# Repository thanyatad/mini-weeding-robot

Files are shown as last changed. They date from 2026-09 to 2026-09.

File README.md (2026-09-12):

# Mini Smart Weeding Robot

POC หุ่นยนต์เกษตรแบบ **rover 4 ล้อ วิ่งระหว่างแถวปลูก** —
NVIDIA Isaac Sim + Python + Computer Vision + Raspberry Pi + ESP32

เป้าหมาย: เริ่มพัฒนาจาก Simulation ก่อน แล้วเปลี่ยนไปใช้ Hardware จริงภายหลัง
โดยไม่ต้องรื้อ architecture หลัก

---

## First MVP — วิ่ง + มองเห็น

MVP แรกทำสองอย่างเท่านั้น: **เดินตามร่องด้วยกล้อง** และ **ตรวจจับวัชพืชในร่อง**

```text
✓ เดินตามร่องระหว่างแถวปลูกด้วยกล้องหน้า
✓ ตรวจจับวัชพืชในร่องด้วยกล้องล่าง แล้วบันทึก log
✗ ไม่กำจัดวัชพืช — ไม่มี tool ไม่มี servo
```

การกำจัดวัชพืชอยู่ที่ **M3** พร้อมงาน tool ทั้งชุด — ดู [Roadmap](#roadmap)

เหตุผล: mobility + perception เป็นความเสี่ยงที่ยังไม่ถูกพิสูจน์
แก้ทีเดียวพร้อม actuator จะแยกไม่ออกว่าอะไรพัง

Design เต็ม: **[docs/superpowers/specs/2026-09-12-rover-base-v0-scale-up-design.md](docs/superpowers/specs/2026-09-12-rover-base-v0-scale-up-design.md)**

Scale-up เป็นเครื่องภาคสนามขนาดจริง (650 × 520 mm, ล้อ Ø250, ~35 kg — ไม่ใช่
เครื่องเดโมบนโต๊ะ 145 mm เดิม): **[docs/superpowers/specs/2026-09-12-rover-base-v0-scale-up-design.md](docs/superpowers/specs/2026-09-12-rover-base-v0-scale-up-design.md)**

---

## Core Principle

> Controller ต้องไม่รู้ว่ากำลังควบคุม Simulation หรือ Hardware จริง

```text
Simulation != Controller
Controller != Hardware
Hardware   != Perception
Perception != Simulation
```

ทุก layer เชื่อมกันผ่าน **Interface** เท่านั้น

หลักการนี้รอดจากการเปลี่ยน form factor ทั้งเครื่อง — ตอนเลิก gantry มาใช้ rover
`Rover`/`CameraSet` interface ถูกเขียนใหม่ แต่ **pattern การเลือก backend
และเส้นแบ่งชั้นไม่ต้องแตะเลย**

---

## High-Level Architecture

```text
     ┌──────────────────────┐      ┌──────────────────────┐
     │   camera_front       │      │    camera_down       │
     │   row following      │      │   weed detection     │
     └──────────┬───────────┘      └──────────┬───────────┘
                ▼                             ▼
     ┌──────────────────────┐      ┌──────────────────────┐
     │    RowEstimate       │      │     Detection[]      │
     └──────────┬───────────┘      └──────────┬───────────┘
                ▼                             ▼
     ┌──────────────────────┐             weed_log
     │      Controller      │        (observation path)
     │  RowFollower         │
     │  State Machine       │
     │  Safety              │
     └──────────┬───────────┘
                ▼
     ┌──────────────────────┐
     │   Rover Interface    │   drive(v, omega) · stop() · emergency_stop()
     └──────────┬───────────┘
    ┌───────────┴───────────┐
    ▼                       ▼
┌─────────────┐     ┌─────────────┐
│ IsaacRover  │     │ Esp32Rover  │
└──────┬──────┘     └──────┬──────┘
       ▼                   ▼
 Isaac Sim            ESP32 (serial)
                           │
                  ┌────────┼────────┐
                  ▼        ▼        ▼
             H-bridge  E-stop   Watchdog
                  │     sense
                  ▼
         DC gear motor × 4  (skid-steer)
```

---

## The Machine

Rover skid-steer 4 ล้อ วิ่งในร่องระหว่างแถวปลูก

```text
Bed                       2000 × 1000 mm
Crop rows                 3 แถว ตามยาว
row_spacing               750 mm      กึ่งกลางแถวถึงกึ่งกลางแถว
clear furrow              690 mm      ◄── ค่าที่ rover ใช้จริง
Soil                      heightfield ผิวไม่เรียบ ±15 mm ไม่ยุบตัว
Rover                     skid-steer 4WD · เครื่องภาคสนาม ~35 kg · กว้างรวมล้อ 520 mm · ล้อ Ø250 mm
Cameras                   front (nav, ไม่ calibrate) + down (detect, homography) — ทั้งคู่บน mast เดียวกัน
Compute                   Raspberry Pi 5 ← serial → ESP32
```

**machine class**: นี่คือเครื่องภาคสนามขนาดจริง (650 × 520 mm, ~35 kg) ไม่ใช่
เครื่องเดโมบนโต๊ะขนาด 200 × 145 mm ของรอบพัฒนาก่อนหน้า — ตัวเลขทุกตัวในเอกสารนี้
คือของ Rover Base V0 ดู [scale-up design](docs/superpowers/specs/2026-09-12-rover-base-v0-scale-up-design.md)

**`row_spacing` ไม่ใช่ความกว้างที่ rover วิ่งได้** — ใบพืชยื่นเข้ามาข้างละ ~30 mm
ค่าที่ใช้จริงคือ `clear_furrow = row_spacing − 2 × crop_foliage_half_width`
invariant ทุกข้อที่เกี่ยวกับช่องว่างด้านข้างใช้ค่านี้

---

## ไม่มี Odometry — และผลที่ตามมา

MVP ไม่มี encoder ไม่มี localization ไม่มีแผนที่ ผลที่ต้องรู้ก่อนเขียน code:

```text
ไม่มี get_position()         ไม่มีอะไรตอบได้
ไม่มี drive_distance(mm)     จะ implement ได้แค่ velocity × time ซึ่งอ้างความแม่นที่ไม่มีจริง
ไม่มีพิกัดวัชพืชในแปลง        weed_log นับ "การตรวจจับ" ไม่ใช่ "จำนวนต้น"
โซ่ frame ขาดที่ bed → rover  ทุกอย่างใต้ rover ทำงานใน rover frame เท่านั้น
```

ใครเขียน code ที่ต้องการพิกัดใน `bed` frame ต้องหยุดแล้วไปทำ **M2 (encoder)**
ไม่ใช่เดาค่ามาเติม — ดู [hardware/mechanical/coordinate-frames.md](hardware/mechanical/coordinate-frames.md)

---

## Safety — 3 ชั้น 3 เจ้าของ

| กลไก | เจ้าของ | เงื่อนไข trip |
|---|---|---|
| Command timeout | **ESP32 firmware** | ไม่ได้รับ velocity command เกิน `command_timeout_ms` |
| Row-loss watchdog | **controller** | estimate invalid ติดกัน `row_loss_frames` |
| Latching E-stop | **hardware** | คนกด — ตัด motor rail ทางไฟ |

**แต่ละชั้นทำงานได้โดยไม่ต้องพึ่งชั้นบน** — Pi แครช มอเตอร์ก็ดับ ·
firmware แฮงค์ ก็ยังตัดไฟได้ ถ้าชั้นใดพึ่งชั้นบน มันไม่ใช่ safety layer มันคือ feature

MVP **ไม่มี bumper switch** ตัวชดเชยคือ `runaway_budget_mm` ที่ validate ตอน startup
+ ขอบแปลงยกสูงกว่าล้อ + ความเร็วต่ำ

---

## Startup Invariants

ความปลอดภัยที่พึ่งตัวเลขใน config ต้องถูก validate ตอน startup ไม่ใช่หวังว่าจะตั้งถูก

```text
safety      v_max × command_timeout/1000        <= runaway_budget         48 <= 60
safety      v_max × row_loss_frames/loop_hz     <= runaway_budget         48 <= 60
geometry    wheel_diameter        >= 4 × soil_variation                  250 >= 60
geometry    chassis_clearance     >  soil_variation                      125 >  15
geometry    clear_furrow          >  body_width + 2 × runaway_budget     690 > 640
drive       v + omega_max_rad × track/2  <= wheel_v_max               253.8 <= 327
drive       v − omega_max_rad × track/2  >= wheel_v_min                66.2 >=  51
config      gains[backend] ไม่เป็น null
consistency simulation.soil.variation_mm == bed.soil_variation_mm
```

ทุกข้อ fail = **ไม่ start** + บอกค่าที่ขัดกันเป็นตัวเลข ไม่ใช่ warning

ตัวเลขในโปรเจกต์นี้ถูกแก้หลายรอบเพราะ invariant จับได้ตอนร่างเอกสาร ไม่ใช่ตอน debug —
รอบ MVP เดิม (เครื่อง 145 mm): `row_spacing` (250 → 350) · `omega_max`
(60 → 40 เพราะ deadband มอเตอร์) · นิยามข้อ 5 (`row_spacing` → `clear_furrow`
เพราะใบพืชกินร่อง) · `track_width` (140 → 120 เพราะ `body_width` ต้องหมายถึง
ความกว้าง**รวมล้อ** ไม่ใช่แค่แชสซี) — รอบ scale-up นี้ (เครื่อง 520 mm):
`row_spacing` (350 → 750) · `track_width` (120 → 430) · `omega_max`
(40 → 25 ที่ track ใหม่) ดู [docs/superpowers/specs/2026-09-12-rover-base-v0-scale-up-design.md §7](docs/superpowers/specs/2026-09-12-rover-base-v0-scale-up-design.md)

ดู [config/README.md](config/README.md#startup-invariants) · [controller/README.md](controller/README.md#startup-validation)

---

## Repository Layout

| Path | Responsibility | Docs |
|---|---|---|
| `cad/` | parameters, exports, URDF — **ต้นทางของขนาดทุกตัว** | [cad/README.md](cad/README.md) |
| `hardware/` | เครื่องจริง — BOM, ขนาด, ประกอบ, สายไฟ, coordinate frames | [hardware/README.md](hardware/README.md) |
| `sim/isaac/` | Physics, แปลงดิน, sensor, rover model, simulation I/O | [docs/simulation.md](docs/simulation.md) |
| `controller/` | Robot brain — row follower, state machine, safety, startup checks | [controller/README.md](controller/README.md) |
| `perception/` | ExG, row estimator, weed detector, weed log, calibration | [perception/README.md](perception/README.md) |
| `firmware/esp32/` | Skid-steer mixing, command timeout, motor enable, E-stop sense | [docs/hardware.md](docs/hardware.md) |
| `bridge/` | Serial transport ระหว่าง Controller ↔ ESP32 / Simulation | [bridge/README.md](bridge/README.md) |
| `protocol/` | Message contract (JSON) shared by all layers | [docs/protocol.md](docs/protocol.md) |
| `config/` | YAML parameters — never hard-code in source | [config/README.md](config/README.md) |
| `tests/` | unit / integration / simulation / scenarios | [tests/README.md](tests/README.md) |
| `scripts/` | Run & flash entry points | [scripts/README.md](scripts/README.md) |
| `tools/` | Calibration, dataset, visualization utilities | [tools/README.md](tools/README.md) |

Full architecture rationale: **[docs/architecture.md](docs/architecture.md)**

---

## Asset Pipeline

Geometry ทั้งหมดเกิดที่ `cad/parameters/parameters.csv` แล้วไหลไป simulation —
ไม่มีใครวาดของซ้ำสอง CAD assembly (ซึ่งตอนนี้ยังไม่มี) **ไม่ใช่** ต้นทางของ geometry ที่ sim ใช้
(ดู [cad/README.md#pipeline](cad/README.md#pipeline) สำหรับรายละเอียดเต็ม):

```text
cad/parameters/parameters.csv          ◄── source of truth: geometry
   │
   ├── (sync)  ──> config/rover.yaml · hardware/mechanical/dimensions.md
   │
   ├── tools/generate_sim_meshes.py ──> cad/exports/meshes/ · cad/urdf/meshes/
   │                                     (generated — ห้ามแก้ด้วยมือ)
   │                                          │
   │                                          ▼
   │                                   cad/urdf/weeding_rover.urdf
   │                                          │  Isaac URDF importer
   │                                          ▼
   │                    sim/isaac/robots/rover/rover_base.usd    generated, gitignored
   │                                          │  + USD layer
   │                                          ▼
   │                    sim/isaac/robots/rover/rover.usd         physics tuning, commit
   │
   └── CAD assembly (งานมือ — ยังไม่มี) ────────> cad/exports/step/ · cad/exports/stl/
                                                       (สำหรับผลิตเท่านั้น)
```

**`parameters.csv` เป็นเจ้าของ geometry · `config/` เป็นเจ้าของ operational limits**
ค่าที่ derived จาก CAD มีตารางกำกับใน [cad/parameters/README.md](cad/parameters/README.md)
และมี `tests/unit/test_cad_config_sync.py` จับ drift

เส้นแบ่ง: *วัดด้วยเวอร์เนียร์ได้ = CAD · เปลี่ยนได้โดยไม่ต้องถอดสกรู = config*

⚠️ ข้อยกเว้นที่ rover มีแต่ gantry ไม่มี: **`camera_front_tilt_deg` ผูกกับ gain ของ controller**
มุมก้มกำหนด lookahead distance ขยับขายึดกล้องแล้ว gain ที่ tune ไว้ใช้ไม่ได้

---

## Backend Selection

Implementation ถูกเลือก **ตอน startup เท่านั้น** — ไม่มี `if simulation:` กระจายใน codebase

```yaml
# config/development.yaml
backend: isaac   # isaac | esp32 | fake
```

| Backend | Use case |
|---|---|
| `fake` | Unit test, closed-loop row following โดยไม่เปิด Isaac |
| `isaac` | Software-in-the-Loop, simulation test, digital twin |
| `esp32` | Hardware-in-the-Loop และ Real machine |

---

## Development Phases

```text
V0  Fake Rover        → Rover interface, RowFollower, state machine, safety, protocol
                        + closed loop ด้วย FakeRover (ไม่ต้องมีกราฟิก)
V1  Isaac Simulation  → rover USD, physics tuning (งานหนักสุด), row estimator, scenarios
V2  Computer Vision   → weed detector กล้องล่าง + evaluation harness เทียบ ground truth
V3  ESP32 HIL         → firmware จริงบนโต๊ะ ล้อลอย — mixing, timeout, E-stop, deadband
V4  Real Hardware     → rover จริงในแปลงจริง — tune gain ใหม่, วัด runaway budget
```

**น้ำหนักงานย้ายจาก design เดิม**: gantry หนักที่ V2 (แยก crop/weed)
rover หนักที่ **V1** (physics ของล้อบน heightfield) — วางแผนเวลาตามนี้

### V0 ปิดลูปได้โดยไม่ต้องมีกราฟิก

```text
FakeRover        integrate (v, omega) → pose ภายใน    (kinematic only)
FakeRowSensor    pose + สมการเส้นร่อง → RowEstimate
RowFollower      RowEstimate → (v, omega)
                        └──> วนกลับเข้า FakeRover
```

ตอบคำถาม *"gain ชุดนี้ลู่เข้าไหม และแกว่งเกินร่องไหม"* ได้ในหลักมิลลิวินาที อยู่ใน CI ได้
ก่อนแตะ Isaac เลย

⚠️ `FakeRover` มี pose ภายใน แต่ **ห้าม expose ผ่าน `get_drive_state()`** —
ถ้าหลุดออกมา code ที่เขียนตอน V0 จะพึ่งพา pose แล้วพังทั้งหมดตอนเปลี่ยนเป็น `esp32`

### MVP Acceptance Criteria

```text
V0  ไม่ต้องมี Isaac
[ ] FakeRover closed loop: เริ่มเบี่ยง 60 mm + เอียง 15° → |lateral_err| < 0.1 ใน 3 s
[ ] ระหว่างลู่เข้า ไม่มีจังหวะที่ระยะถึงต้นพืชติดลบ
[ ] golden mixing vectors ผ่านทั้ง Python และ firmware (native env)
[ ] startup invariant ทั้ง 9 ข้อ fail จริงเมื่อป้อนค่าที่ขัดกัน (test ละข้อ)
[ ] get_drive_state() คืน key ชุดเดียวกันทั้ง fake / isaac / esp32
[ ] ภาพดินเปล่า → exg mask ว่าง (ไม่ให้ Otsu แบ่ง noise)

V1  Isaac
[ ] rover วิ่งร่องตรง 2000 mm จบ ไม่เบียดต้นพืช
[ ] ร่องโค้ง 40 mm วิ่งจบ
[ ] เริ่มเอียง 15° เข้าร่องได้
[ ] ผิวดิน ±15 mm ยังตามร่องได้ (ล้อลอยเป็นช่วง)
[ ] ช่องว่างกลางแถว → ไม่หยุด
[ ] สุดร่อง → STOPPED(row_end_suspected)
[ ] ถอดแถวแต่ยังมีเขียว → ERROR(row_lost)
[ ] front loop >= 10 Hz
[ ] วัด max_lateral_error + crop_foliage_half_width จริง แล้ว re-validate invariant ข้อ 5

V2  Perception
[ ] weed detector per-frame precision >= 0.9
[ ] weed detector per-frame recall >= 0.8  (วัชพืชในร่องเท่านั้น)
[ ] วัดกับ randomization เปิดครบ ไม่ใช่ seed เดียว

V3  HIL — ล้อลอย
[ ] ถอดสาย serial → มอเตอร์ดับภายใน 300 ms (วัดด้วย scope หรือ log timestamp)
[ ] กด E-stop → ล้อหยุด ขณะที่ Pi ยังส่ง drive อยู่
[ ] ยัด drive 50 ตัวเข้า buffer → ESP32 ใช้ตัว seq สูงสุดตัวเดียว
[ ] ส่ง seq ย้อนหลัง → ถูกทิ้ง
[ ] วัด wheel_v_min_mm_s จริง แล้ว re-validate invariant drive ตัวล่าง

V4  แปลงจริง
[ ] 2 กล้องพร้อมกันบน Pi โดย front ยัง >= 10 Hz
[ ] tune gain esp32 แล้วบันทึกลง control.yaml (ไม่ใช้ค่า isaac)
[ ] วัด runaway distance จริง <= runaway_budget_mm
[ ] วัด homography error จริง บันทึกลง camera.yaml
[ ] วิ่งจบร่อง 2000 mm ในแปลงจริง 3 ครั้งติด
```

เกณฑ์ทุกข้อ **วัดได้** — ไม่มีข้อไหนเขียนว่า "ทำงานได้" โดยไม่บอกว่าวัดอย่างไร

---

## รั้วขอบเขต — สิ่งที่ MVP ไม่ทำ

เขียนไว้ชัดเพื่อไม่ให้ไหลเข้ามาทีละข้อ

```text
✗ ไม่กำจัดวัชพืช — ไม่มี tool ไม่มี servo
✗ ไม่เลี้ยวเข้าร่องถัดไป — วิ่งร่องเดียวแล้วหยุด
✗ ไม่มีพิกัดวัชพืชในแปลง — ไม่มี odometry
✗ ไม่ dedupe การตรวจจับ — log นับ detection ไม่ใช่นับต้น
✗ ไม่เห็นวัชพืชในแถว — เห็นแค่ในร่อง
✗ ไม่มี obstacle avoidance — ไม่มี bumper ไม่มี ToF
✗ ไม่มี turn-in-place — v = 0 กับ omega ใด ๆ อยู่ใน deadband ทั้งสองล้อ
✗ ไม่มี suspension
✗ ไม่มี ROS2 · ไม่มี MQTT · ไม่มี Wi-Fi ใน control path
```

---

## Roadmap

| M | เนื้อหา | ทำไมต้องลำดับนี้ |
|---|---|---|
| **M1** | **rover MVP — วิ่ง + มองเห็น** (ที่กำลังทำ) | พิสูจน์ mobility + perception ก่อนเพิ่ม actuator |
| **M2** | wheel encoder → ระยะตามแถว, dedupe, weed map | ต้องมาก่อน tool: tool ต้องเล็ง และการเล็งต้องรู้ตำแหน่ง |
| **M3** | tool + soil contact + in-row detection | ยกงาน tool จาก spec แปลงดินกลับมาใช้ได้เกือบทั้งหมด |
| **M4** | เลี้ยวเข้าร่องถัดไป → cover ทั้งแปลง | ต้องมี odometry จาก M2 ถึงจะเลี้ยวแบบไม่เห็นเป้าหมายได้ |
| **M5** | AI detector แทน ExG | dataset จาก M1–M3 มี background ดินจริงแล้ว |

---

## Technology Stack

| Component | Technology |
|---|---|
| Simulation | NVIDIA Isaac Sim |
| Controller | Python (บน Raspberry Pi) |
| Computer Vision | OpenCV / PyTorch |
| Firmware | ESP-IDF / Arduino |
| Firmware Build | PlatformIO |
| Communication | Serial (JSON lines) |
| Config | YAML |
| Protocol | JSON |
| Testing | pytest |
| Scenario Testing | YAML |
| Robot Model | USD |
| Version Control | Git |

---

## Why Not ROS2 (yet)

MVP นี้มี **1 หุ่นยนต์ 2 กล้อง 4 มอเตอร์ 1 E-stop** — ไม่มี SLAM ไม่มี path planning
ไม่มี MoveIt row following เป็น reactive controller ตัวเดียวที่รับ `RowEstimate`
คืน `(v, omega)` ไม่มี node graph ให้จัดการ

Python + Isaac Sim API + Rover abstraction ง่ายกว่าและเพียงพอ

ควรเพิ่ม ROS2 เมื่อมี: **Nav2 / SLAM จริง**, robot หลายตัว, sensor หลายชุด,
distributed process, hardware driver หลายชนิด, MoveIt / ROS Control

M4 (เลี้ยวเข้าร่องถัดไป + cover ทั้งแปลง) เป็นจุดที่ควรกลับมาทบทวนข้อนี้อีกครั้ง

---

## Design History

| Document | Status |
|---|---|
| [docs/superpowers/specs/2026-09-12-rover-base-v0-scale-up-design.md](docs/superpowers/specs/2026-09-12-rover-base-v0-scale-up-design.md) | **Current** — Rover Base V0, 650 × 520 mm, ล้อ Ø250 |

spec รุ่นก่อน (rover MVP ล้อ Ø70 และ gantry คร่อมแปลง) ถูกลบออกจาก tree แล้ว — อยู่ใน git history
| `mini-smart-weeding-table-repository-architecture.md` | ลบแล้ว — design โต๊ะ + ถาด อยู่ใน git history เท่านั้น |

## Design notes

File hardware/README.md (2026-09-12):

# hardware

เอกสารของเครื่องจริง — สิ่งที่จับต้องได้ ประกอบได้ และวัดได้

```text
hardware/
├── bom/
│   └── poc-v3.md               requirement envelope + ข้อกำหนดที่ต้องตรวจก่อนซื้อ
│
├── mechanical/
│   ├── dimensions.md           ขนาดทั้งหมด (derived จาก CAD)
│   ├── assembly.md             ลำดับประกอบ + ค่าที่ต้องวัดระหว่างทาง
│   └── coordinate-frames.md    นิยาม frame ทุกตัวในระบบ
│
└── electrical/
    ├── wiring.md               pin map + กับดักของ ESP32
    └── power.md                budget + topology + safety
```

---

## เริ่มอ่านจากไหน

| ถ้าคุณกำลัง… | อ่าน |
|---|---|
| ประเมินงบ / จะซื้อของ | [bom/poc-v3.md](bom/poc-v3.md) |
| ประกอบ rover | [mechanical/assembly.md](mechanical/assembly.md) |
| เดินสาย | [electrical/wiring.md](electrical/wiring.md) → [electrical/power.md](electrical/power.md) |
| เขียน firmware | [electrical/wiring.md](electrical/wiring.md) + [../docs/hardware.md](../docs/hardware.md) |
| เขียน perception / row follower | [mechanical/coordinate-frames.md](mechanical/coordinate-frames.md) |
| แก้ขนาด rover | [../cad/parameters/README.md](../cad/parameters/README.md) |

---

## `hardware/` กับ `docs/hardware.md` ต่างกันยังไง

| | ขอบเขต |
|---|---|
| `hardware/` | **เครื่องจริง** — ของที่ซื้อ, ขนาด, การประกอบ, สายไฟ, แปลงทดสอบ |
| `docs/hardware.md` | **firmware & integration** — ESP32 ทำอะไร, mixing, timeout, build/flash, HIL |

เส้นแบ่ง: *ถ้าต้องใช้ไขควง = `hardware/` · ถ้าต้องใช้ compiler = `docs/hardware.md`*

---

## เอกสารนี้ไม่ใช่ต้นทางของตัวเลข

ขนาดทุกตัวใน `mechanical/dimensions.md` เป็น **derived จาก CAD**

```text
cad/parameters/parameters.csv   ◄── ต้นทาง
   ├─► hardware/mechanical/dimensions.md   (เอกสาร)
   ├─► config/rover.yaml                   (runtime)
   ├─► cad/urdf/weeding_rover.urdf         (simulation)
   └─► config/drive_mixing_vectors.csv     (firmware + sim)

CAD assembly (ยังไม่มี) ──► cad/exports/step/ · cad/exports/stl/   (งานผลิตเท่านั้น)
```

ถ้าตัวเลขที่นี่ขัดกับ `parameters.csv` → **CSV ถูก** แล้วเอกสารนี้ล้าสมัย

ตรวจ drift ด้วย:

```bash
pytest tests/unit/test_cad_config_sync.py
```

---

## ค่าที่เอกสารชุดนี้ยัง **เดา** อยู่

ตัวเลขในเอกสารชุดนี้เป็นค่าเริ่มต้นที่สอดคล้องกัน ไม่ใช่ค่าที่วัดจากของจริง
ห้าเก้าค่าต่อไปนี้ต้องวัดแล้วเขียนกลับก่อนเชื่ออะไรที่สืบทอดจากมัน

| ค่า | วัดที่ | ถ้าผิดแล้วเกิดอะไร |
|---|---|---|
| `wheel_v_min_mm_s` | V3 ล้อลอย | `omega_max` สูงเกิน ล้อข้างในหยุดเงียบ |
| `body_width_mm` (จุดกว้างสุด) | หลังใส่ล้อ | invariant ข้อ 5 ผ่านโดยที่ล้อยังเบียดใบพืช |
| `chassis_clearance_mm` (พร้อมโหลด) | หลังประกอบครบ | ท้องครูดยอดดินที่ invariant บอกว่าผ่าน |
| `crop_foliage_half_width_mm` | V1 asset พืช | กระทบ invariant ข้อ 5 **และ** corridor พร้อมกัน |
| `soil_variation_mm` | หลังปรับหน้าดิน | เกิน 62 mm → invariant `wheel_diameter ≥ 4 × soil_variation` ไม่ผ่าน (ล้อ Ø250 ให้ margin 190 mm ที่ 15 mm — กว้างกว่าเดิมมาก ไม่ใช่จุดเสี่ยงหลักของเครื่องนี้แล้ว) |
| `runaway_budget_mm` | หลังวางลงแปลง | ค่าความปลอดภัยหลักของ MVP |
| FOV กล้องล่างจริง | ก่อนสั่งกล้อง | เห็นร่องไม่ครบ → ใบพืชผลถูกนับเป็นวัชพืช |
| `error_budget_mm` (homography) | หลัง calibrate | ตัวเลขใน weed log ไม่มีความหมาย |
| `gains.esp32` | V4 tune | ค้างเป็น `null` = ไม่ start (ตั้งใจ) |

---

## กับดักที่เอกสารชุดนี้เขียนไว้ให้แล้ว

เรื่องที่เสียเวลา debug มากที่สุดถ้าไม่รู้ก่อน — เรียงตามความเจ็บ

| เรื่อง | ที่ |
|---|---|
| **`omega` กลับด้าน → row follower เป็น positive feedback** | [electrical/wiring.md](electrical/wiring.md#ตรวจทิศทางก่อนปิดฝา) |
| **ESP32 กินไฟจาก Pi ทำให้ safety เหลือ 2 ชั้นไม่ใช่ 3** | [electrical/power.md](electrical/power.md#️-esp32-ต้องไม่กินไฟจาก-pi) |
| **Pi รีบูตตอนมอเตอร์ออกตัว (buck ตัวเดียว)** | [electrical/power.md](electrical/power.md#️-ต้องมี-buck-สองตัว--ไม่ใช่หนึ่ง) |
| **มอเตอร์เร็วเกินทำให้อยู่ใน deadband ตลอดเวลา** | [mechanical/dimensions.md](mechanical/dimensions.md#️-มอเตอร์ที่เร็วกว่า-แย่กว่า-ไม่ใช่ดีกว่า) |
| **`body_width` ≠ ความกว้างแชสซี (ล้อยื่นออก)** | [mechanical/dimensions.md](mechanical/dimensions.md#️-body_width--ความกว้างแชสซี) |
| **`camera_front_tilt` ผูกกับ gain — ไม่มี test จับ** | [mechanical/coordinate-frames.md](mechanical/coordinate-frames.md#️-แต่-extrinsic-ผูกกับ-gain) |
| ล้อซ้าย/ขวาคนละขนาด → ดูเหมือน gain ผิด | [mechanical/assembly.md](mechanical/assembly.md#ล้อคนละขนาดคือกับดักที่หายากที่สุด) |
| GPIO 34/35/36/39 ไม่มี internal pull-up | [electrical/wiring.md](electrical/wiring.md#️-gpio-34-35-36-39-ไม่มี-internal-pull-up) |
| E-stop ที่ตัด logic ด้วย → รายงานสถานะไม่ได้ | [electrical/power.md](electrical/power.md#e-stop-ตัดแค่-motor-rail) |
| soil reference plane ≠ ผิวดินจริง | [mechanical/coordinate-frames.md](mechanical/coordinate-frames.md#bed--ยังนิยามไว้-เพราะ-sim-และเอกสารต้องใช้) |
| mm ↔ m และ deg ↔ rad ที่รอยต่อ URDF | [mechanical/coordinate-frames.md](mechanical/coordinate-frames.md#unit-convention) |
| เสากล้องโยก → ภาพสั่น → `omega` กระตุก | [electrical/wiring.md](electrical/wiring.md#cable-management) |
| แบตอ่อน → deadband กินพิสัย `omega` แบบเงียบ | [electrical/power.md](electrical/power.md#low-voltage-behaviour) |

สามรายการบนสุดเป็นกลุ่มที่ **ทำให้ระบบดูเหมือนทำงานแล้วพังในแปลง** —
อ่านก่อนจ่ายไฟครั้งแรก

---

## ⚠️ MVP นี้ไม่ควรรันโดยไม่มีคนดู

```text
ไม่มี bumper switch
ไม่มี ToF / ultrasonic
ไม่มี obstacle avoidance
ไม่มี encoder จะรู้ว่าล้อหมุนจริงไหม
```

ตัวชดเชยทางกายภาพมีแค่สองอย่าง: **ขอบแปลงยกสูงกว่ารัศมีล้อ** และ
**`runaway_budget_mm` ที่ validate ตอน startup**

ถ้าขอบแปลงไม่ยก หรือ `runaway_budget` ยังไม่ได้วัดจริง — ต้องมีคนยืนถือ E-stop

ดู [../docs/superpowers/specs/2026-09-12-rover-base-v0-scale-up-design.md](../docs/superpowers/specs/2026-09-12-rover-base-v0-scale-up-design.md#12-risks--สิ่งที่ไม่มี-test-จับได้)

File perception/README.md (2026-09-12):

# perception

สอง pipeline แยกกันสมบูรณ์ แชร์เฉพาะ ExG

```text
                  ┌── exg.py (shared) ──┐
                  ▼                     ▼
camera.front ─> row_estimator.py    weed_detector.py <─ camera.down
                  │                     │
                  ▼                     ▼
             RowEstimate            Detection[]  ──> weed_log.py
             (control path)         (observation path)
```

**control path กับ observation path ต้องไม่ปนกัน** — detection ช้าหรือพลาด
ต้องไม่ทำให้ rover เลี้ยวผิด front ทำงานที่ 10 Hz · down ที่ 1-2 Hz

---

## Responsibility

- Camera input (2 ตัว)
- ExG segmentation
- Row estimate (navigation)
- Weed detection (observation)
- Weed log
- Calibration (กล้องล่างเท่านั้น)

**ไม่** รับผิดชอบ: motion, rover control, row following policy

---

## Layout

```text
perception/
├── cameras.py              # CameraSet interface + Fake / Isaac / Usb
├── exg.py                  # ExG + Otsu + absolute floor       shared
├── row_estimator.py        # front  → RowEstimate
├── weed_detector.py        # down   → Detection[]
├── weed_log.py             # JSONL writer
├── calibration.py          # intrinsic + homography (กล้องล่าง)
└── models/                 # trained weights — ว่างใน MVP (ใช้ที่ M5)
```

ไม่มี `row_detection.py` · ไม่มี `coordinate_transform.py` สำหรับ navigation —
เหตุผลอยู่ที่ [§weed_detector](#weed_detectorpy--เรขาคณิตของ-rover-ทำงานแทน-row-fitting)
และ [§Calibration](#calibration--เหลือแค่กล้องล่าง)

---

## CameraSet Abstraction

```python
class CameraSet(Protocol):

    def front(self) -> Frame:
        """สำหรับ row following"""
        ...

    def down(self) -> Frame:
        """สำหรับ weed detection"""
        ...
```

```text
CameraSet
│
├── FakeCameraSet
├── IsaacCameraSet
└── UsbCameraSet
```

เลือก **named accessor** ไม่ใช่ `capture(camera_id)` เพราะสองกล้องนี้ต่างกันที่
contract ไม่ใช่ต่างกันที่ index:

| | `front()` | `down()` |
|---|---|---|
| ใช้ทำ | row following | weed detection |
| Calibration | **ไม่ต้อง** | homography → mm |
| Rate | 10 Hz (อยู่ใน control loop) | 1-2 Hz |
| ความละเอียด | 640×480 → ย่อ 320×240 | 1280×720 |

`capture(id)` จะซ่อนความต่างนี้ แล้วมีคนเผลอเอาภาพ `front` ไปทำ coordinate transform

### `Frame` — ภาพที่รู้อายุตัวเอง

```python
@dataclass(frozen=True, eq=False)
class Frame:
    image: np.ndarray       # (h, w, 3) RGB
    timestamp_s: float      # monotonic clock ไม่ใช่ epoch
```

`camera_timeout_ms: 300` แปลว่าต้องมีใครสักคนตอบได้ว่าเฟรมนี้เก่าไปหรือยัง
stack ที่มี sensor จริงอยู่ข้างหลังตอบจาก**ตัวเฟรมเอง**ทั้งนั้น — ROS 2 ปั๊ม
acquisition time ลง header ของ `sensor_msgs/Image` · librealsense แขวน
`get_timestamp()` ไว้กับ frame object ข้อยกเว้นคือ `VideoCapture` ของ OpenCV
ที่คืน array เปล่าแล้วให้ไปถามเวลาแยกทาง `CAP_PROP_POS_MSEC` ซึ่งมีเอกสารว่า
คืน `-1` บนกล้องสด — **type alias เป็น ndarray เฉย ๆ คือ design นั้น**

นาฬิกาเป็น monotonic ไม่ใช่ wall clock เพราะคำถามเดียวที่ถาม timestamp คือ
ระยะเวลา ("เกิน 300 ms หรือยัง") และ wall clock เดินถอยหลังได้ตอน NTP แก้เวลา
ซึ่งจะทำให้ check ยิงใส่เฟรมสด หรือปล่อยเฟรมเก่าผ่าน

**`row_estimator.estimate()` รับ `np.ndarray` ไม่ใช่ `Frame`** — ROS แยกแบบเดียวกัน
คือ message พก header ส่วน `cv_bridge` ส่ง array เปล่าให้ algorithm estimator
ต้องการ pixel และไม่มีเรื่องต้องใช้นาฬิกา การใส่ field ที่มันห้ามอ่านลงใน
signature คือการชวนให้มีคนอ่าน

**คนเช็ค timeout ไม่ใช่ perception** `Event.CAMERA_TIMEOUT` อยู่ใน
`row_run.FAULT_EVENTS` ซึ่งเป็นชุดที่ detect *นอก* control loop — หน้าที่ของชั้นนี้
คือทำให้อายุเฟรม*รู้ได้* ไม่ใช่ตัดสินมัน

---

## `exg.py` — ExG + adaptive threshold + absolute floor

```python
exg = 2*G - R - B
if exg.max() < exg_floor:
    return Mask.empty()        # ไม่มีเขียวจริง — ไม่เรียก Otsu
mask = exg > otsu(exg)
```

### ทำไม ExG ไม่ใช่ color threshold ตรง ๆ

**ExG (Excess Green Index)** = `2G − R − B` วัด *ความเขียวเชิงสัมพัทธ์*
ไม่ใช่ค่าสีดิบ จึงทนต่อการเปลี่ยนแปลงของแสงและสีดินมากกว่า
เป็น index มาตรฐานในงาน agricultural vision

ดินแห้งกับดินเปียกสีต่างกันมาก — threshold คงที่บนค่าสีดิบต้อง tune ใหม่ทุกครั้งที่รดน้ำ

### ทำไม Otsu ต่อเฟรม ไม่ใช่ค่าคงที่

สีดินเปลี่ยนตามความชื้นและแสง Otsu หา threshold จากฮิสโทแกรมของเฟรมนั้นเอง
ไม่ต้องมีใครมาตั้งค่า

### ⚠️ จุดตายของ Otsu — และเหตุผลของ `exg_floor`

**เมื่อไม่มีสีเขียวในเฟรมเลย Otsu จะแบ่ง noise ออกเป็นสองกอง** แล้วคืน mask
ที่ดูเหมือนมีพืช ทำให้ heuristic `row_end` ตรวจไม่เจอว่าสุดร่องแล้ว

`exg_floor` เป็นพื้นกันข้อนี้ และเป็น **ค่าเดียวใน pipeline ที่ต้อง tune ด้วยมือ**

ต้องมี unit test ป้อนภาพดินเปล่ายืนยันว่าได้ mask ว่าง — อยู่ใน acceptance criteria ของ V0

---

## `row_estimator.py` — valley histogram ไม่ใช่ line fitting

สิ่งที่ rover ต้องตามคือ **ร่องดิน** ซึ่งคือหุบเขาระหว่างแถบเขียวสองแถบ

```text
column-wise green sum ของแถบภาพหนึ่งแถบ:

  ███                       ███        ← แถวพืชซ้าย / ขวา
  ███▄                     ▄███
  █████▄        ▼         ▄█████
  ───────────────────────────────────  u
              valley = กลางร่อง
```

สองแถบ สองหน้าที่:

```python
valley_near = find_valley(mask[bottom_third])    # ใกล้ล้อ
valley_far  = find_valley(mask[middle_third])    # lookahead

lateral_err = (valley_near - u_center) / (width / 2)
heading_err = (valley_far - valley_near) / (width / 2)
confidence  = valley_prominence                  # ความลึกของหุบเทียบยอดสองข้าง
valid       = confidence > conf_min  (ทั้งสองแถบ)
```

### `RowEstimate`

```python
@dataclass(frozen=True)
class RowEstimate:
    valid: bool
    lateral_err: float      # [-1, 1]  ร่องเบี่ยงจากกลางภาพ  (+ = ร่องอยู่ขวา)
    heading_err: float      # [-1, 1]  ความเอียงของเส้นร่องในภาพ  (+ = เอียงขวา)
    confidence: float       # [0, 1]
    green_fraction: float   # [0, 1]  สัดส่วน pixel ที่ ExG ผ่าน threshold
```

**ไม่มีหน่วย mm หรือ deg ทั้ง struct โดยเจตนา** — กล้องหน้าไม่ calibrate
ค่าที่วัดได้จากภาพที่ไม่ calibrate คือ pixel ratio ถ้าประกาศเป็น mm หรือ deg
จะเป็นการอ้างหน่วยที่ไม่มีใครยืนยันได้

gain ของ controller จึงมีหน่วย `(deg/s) / unitless` และ **ต้อง tune** —
ยอมรับตรง ๆ ดีกว่าซ่อนใต้หน่วยปลอม

### ทำไม valley histogram แทน line fitting / Hough

| | valley histogram | line fitting |
|---|---|---|
| ต้นหายกลางแถว | ทนได้ — histogram ยังเห็นแถบ | เสี่ยง fit เพี้ยนเพราะ blob หาย |
| ร่องโค้ง | ทนได้ — วัดสองระยะแยกกัน ไม่บังคับเป็นเส้นตรง | ต้อง fit เส้นโค้ง ซับซ้อนขึ้น |
| ต้นทุน | numpy sum + argmin ทัน 10 Hz บน Pi สบาย | Hough แพงกว่ามาก |
| Debug | plot histogram เห็นทันทีว่าพลาดที่ไหน | ต้องดู blob + parameter หลายตัว |

`heading_err` จากผลต่างของ valley สองระยะ **ไม่ต้องรู้ geometry กล้องเลย**

`valley_prominence` เป็น confidence ที่มีความหมายทางกายภาพ: ถ้าแถบเขียวสองข้าง
แยกจากหุบไม่ชัด แปลว่าไม่เห็นร่อง ซึ่งควรทำให้ `valid = False` จริง ๆ
ไม่ใช่ค่าที่ตั้งเอาใจให้ผ่าน

### ⚠️ ผูกกับ `camera_front_tilt_deg`

มุมก้มกำหนดว่า `valley_far` อยู่ห่างไปข้างหน้าเท่าไร = **lookahead distance**
ขยับขายึดกล้องแล้ว gain ที่ tune ไว้ใช้ไม่ได้ ดู [../config/README.md](../config/README.md#controlyaml)

---

## `weed_detector.py` — เรขาคณิตของ rover ทำงานแทน row fitting

design gantry ต้อง fit เส้นแถวเพื่อแยก crop จาก weed เพราะมองทั้งแปลงจากด้านบน
พืชผลกับวัชพืชอยู่ในเฟรมเดียวกัน

rover กลับด้านปัญหานี้: **กล้องล่างเล็งที่ร่อง และพืชผลไม่ได้ปลูกในร่อง**

```text
สีเขียวในร่อง = วัชพืช  โดยนิยาม
```

ไม่ต้อง classifier ไม่ต้อง row fitting ไม่ต้องเทียบขนาดกับพืชผล:

```python
mask = exg_mask(down_frame)
for blob in blobs(mask):
    if blob.touches_side_edge:                     continue   # ใบพืชผลที่ล้ำเข้ามา
    if blob.centroid_x_mm not in furrow_corridor:  continue
    if blob.area_mm2 < min_weed_area_mm2:          continue
    yield Detection(...)
```

### `furrow_corridor` มาจากเรขาคณิต

```text
clear furrow   row_spacing − 2 × crop_foliage_half_width   750 − 60 = 690 mm
corridor       clear_furrow − 2 × max_lateral_error_mm      690 − 80 = 610 mm
```

`corridor` คือแถบที่ **รับประกันว่าอยู่ในร่อง** แม้ rover เบี่ยงเต็มพิสัย —
สีเขียวในแถบนี้จึงเป็นวัชพืชได้โดยไม่ต้องรู้ว่าแถวอยู่ไหน

กฎ `touches_side_edge` จัดการใบพืชผลที่ยื่นเข้าร่องโดยไม่ต้องรู้ว่ามันคือพืชผล —
ใบที่ต่อเนื่องออกไปนอกเฟรมย่อมไม่ใช่ต้นเล็กที่อยู่กลางร่อง

### สองค่าที่ประกอบกันเป็น corridor ต้องวัดที่ V1 ทั้งคู่

| ค่า | ตั้งไว้ | ถ้าวัดจริงแล้วมากกว่า |
|---|---|---|
| `max_lateral_error_mm` | 40 | corridor แคบลง recall ตก |
| `crop_foliage_half_width_mm` | 30 | clear furrow แคบลง **กระทบ startup invariant ข้อ 5 ด้วย** |

ถ้าค่าที่วัดได้ทำให้ `corridor <= 0` แปลว่า **แปลงแคบเกินไปสำหรับ rover ขนาดนี้**
ไม่ใช่ว่า detector ต้อง tune ใหม่

### ข้อจำกัด: วัชพืชในแถวมองไม่เห็น

in-row weed เป็นกรณี**ยากที่สุด**ของปัญหาจริง และอยู่นอก MVP โดยเจตนา —
เพราะการกำจัดมันต้องมี tool ซึ่งไม่มีใน MVP อยู่แล้ว

**ไม่ควรทำให้ perception ยากกว่าที่ actuator ทำได้** กลับมาที่ M3 พร้อม tool

---

## Calibration — เหลือแค่กล้องล่าง

| | กล้องหน้า | กล้องล่าง |
|---|---|---|
| Calibration | **ไม่มี** | homography → soil reference plane |
| Accuracy target | – | **±20 mm** (ผ่อนจาก ±8 mm ของ design gantry) |

ผ่อนได้เพราะ **MVP ไม่มีอะไรกระทำต่อตำแหน่ง** — ไม่มี tool ที่ต้องเล็ง
ตัวเลข mm ใช้แค่บันทึกขนาด/ตำแหน่งคร่าว ๆ ใน log

แต่ยัง **ต้องทำ** homography ตอนนี้ ไม่เลื่อนทั้งหมด — เพื่อรู้ตัวเลข error budget จริง
บนดิน ±15 mm **ก่อน** ออกแบบ tool ที่ M3 ไม่ใช่หลังจากนั้น

ขั้นตอน: [../docs/calibration.md](../docs/calibration.md)

---

## `weed_log.py` — และข้อจำกัดที่ต้องไม่ให้ใครเข้าใจผิด

```jsonl
{"t":12.34,"frame":123,"lateral_err":0.12,"u":160,"v":200,
 "x_mm":-25,"y_mm":120,"area_mm2":480}
```

`x_mm` / `y_mm` เป็นพิกัด **ใน rover frame** ไม่ใช่ใน bed frame

### ไม่มี weed id และไม่มีพิกัดในแปลง

ไม่มี odometry จึงไม่มีทางรู้ว่าวัชพืชที่เห็นในเฟรม 123 กับ 124 เป็นต้นเดียวกัน
หรือคนละต้น

**log นี้นับ "การตรวจจับ" ไม่ใช่ "จำนวนวัชพืช"** — ตัวเลขรวมจาก log ไม่มีความหมาย
**ห้ามใช้เป็น metric**

### วัดด้วย per-frame precision / recall

```text
per-frame precision >= 0.9
per-frame recall    >= 0.8   (วัดเฉพาะวัชพืชในร่อง)
```

เทียบ ground truth ที่ Isaac รู้อยู่แล้ว — ได้ label ฟรีและวัดได้ทุกเฟรม

recall ตั้งต่ำกว่า precision **โดยเจตนา**: MVP ไม่กำจัดอะไร การพลาดต้นหนึ่ง
ไม่เสียหาย แต่การรายงานดินเป็นวัชพืชจะทำให้ threshold ถูก tune ผิดทางตั้งแต่ต้น

ต้องวัดกับ randomization เปิดครบ ไม่ใช่ seed เดียว

---

## Detection Roadmap

| Stage | Method |
|---|---|
| **M1 (MVP)** | OpenCV — ExG + Otsu + corridor geometry |
| M3 | + in-row detection (ต้องแยก crop/weed จริง ๆ ตอนนั้น) |
| M5 | AI — YOLO / segmentation model |

อย่าเริ่มด้วย Deep Learning — MVP นี้แยก crop/weed ได้ด้วย**เรขาคณิต**
ซึ่งอธิบายได้ debug ได้ และไม่ต้องมี dataset

Dataset สำหรับ M5 generate ได้จาก `tools/dataset/` โดยใช้ ground truth จาก Isaac Sim

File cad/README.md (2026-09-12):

# cad

> ### ⚠️ `cad/fusion/rover_base_v0.f3d` เป็น snapshot ไม่ใช่ working file
>
> Rover Base V0 (650 × 520, ล้อ Ø250) มี assembly แล้ว `exports/step/` และ
> `exports/stl/` ไม่ว่างอีกต่อไป
>
> ```text
> parameters.csv · urdf/ · exports/meshes/   ✓ generated จาก CSV
> fusion/ · exports/step/ · exports/stl/     ✓ มาจาก CAD assembly
> ```
>
> แต่ **ตัวที่แก้ได้อยู่บน Autodesk cloud ไม่ใช่ไฟล์ใน repo** — Fusion save ลง
> cloud project เสมอ ไม่เคย save กลับมาที่นี่:
>
> ```text
> เปิด .f3d  →  Fusion upload เข้า cloud  →  ได้ document ใหม่ คนละตัวกับไฟล์นี้
> กด Save    →  ลง cloud                  →  ไฟล์ใน repo ไม่ขยับ
> ```
>
> **แก้ assembly แล้วต้อง export ทับทั้ง 3 ที่เสมอ** (`fusion/` · `exports/step/` ·
> `exports/stl/`) ไม่งั้นมัน stale เงียบ ๆ — `7e91e59` ลบ `rover.f3d` ตัวเก่าทิ้ง
> เพราะค้างอยู่ที่รถ 200 × 145 ล้อ Ø70 ทั้งที่โปรเจกต์ย้ายไป 650 × 520 แล้ว
>
> `parameters.csv` ยังเป็นต้นทางของ geometry เหมือนเดิม — `.f3d` เก็บไว้กู้ **งาน
> ประกอบ** (user parameter, sketch, constraint) ไม่ใช่กู้ตัวเลขขนาด
>
> `exports/meshes/` **ไม่เกี่ยวกับงานนี้เลย** — `tools/generate_sim_meshes.py`
> สร้างจาก `parameters.csv` ให้แล้ว

Mechanical source of truth — **เรขาคณิตทั้งหมดต้นทางที่ `cad/parameters/parameters.csv`**
งานผลิต (STEP / STL) มาจาก CAD assembly ใน `fusion/` ดู [Pipeline](#pipeline) ด้านล่าง

```text
cad/
├── parameters/
│   ├── README.md               นิยาม parameter + ตาราง derived
│   └── parameters.csv          ต้นทางของ geometry — แก้ตรงนี้ (commit ทุกครั้งที่แก้ขนาด)
│
├── fusion/
│   └── rover_base_v0.f3d       snapshot ของ assembly — ตัวจริงบน cloud (ดูกล่องบนสุด)
│
├── exports/
│   ├── step/                   งานผลิต / review / ส่งร้าน
│   ├── stl/                    3D print
│   └── meshes/                 simplified visual + collision สำหรับ sim
│
└── urdf/
    ├── weeding_rover.urdf      links, joints, limits, mesh refs
    └── meshes/                 mesh ที่ URDF อ้างถึง
```

---

## Pipeline

`cad/parameters/parameters.csv` **คือต้นทางของ geometry** — ไม่ใช่ CAD assembly
สอง path ไหลออกจากมันแยกกัน และไม่มี path ไหนขึ้นกับอีก path (S11):

```text
cad/parameters/parameters.csv          ◄── source of truth: geometry
   │
   ├── tools/generate_sim_meshes.py ──> cad/exports/meshes/ · cad/urdf/meshes/
   │                                     (generated — ห้ามแก้ด้วยมือ)
   │                                          │
   │                                          ▼
   │                                   cad/urdf/weeding_rover.urdf
   │                                          │
   │                                          │  Isaac URDF importer  →  scripts/import_urdf.sh
   │                                          ▼
   │                    sim/isaac/robots/rover/rover_base.usd    ◄── generated, gitignored
   │                                          │
   │                                          │  + USD layer
   │                                          ▼
   │                    sim/isaac/robots/rover/rover.usd         ◄── override layer, commit
   │
   └── CAD assembly (งานมือ, บน cloud) ─> cad/fusion/rover_base_v0.f3d
                                          cad/exports/step/ · cad/exports/stl/
                                             (สำหรับผลิต / review / ส่งร้าน เท่านั้น)
```

`tools/generate_sim_meshes.py` อ่าน `parameters.csv` แล้วเขียน mesh + inertia
tensor ให้ sim โดยตรง — ไม่ผ่าน CAD assembly เลย เพราะงาน assembly เป็นงานมือ
ถ้า sim ต้องรอ งาน development จะหยุด `cad/exports/meshes/` และ
`cad/urdf/meshes/` จึงเป็นไฟล์ **generated** ห้ามแก้ด้วยมือ — แก้ที่
`parameters.csv` แล้วรัน generator ใหม่เสมอ

**path ล่างมีของแล้ว** assembly ขึ้นรูปจาก `parameters.csv` และผูก user parameter
ไว้ทุกตัว แต่มันยังตามมาทีหลังได้โดยไม่บล็อกใคร (design §9.1) — นี่คือเหตุผลที่ sim
ไม่ถูกผูกกับมันตั้งแต่แรก และยังไม่ควรผูก

### ทำไมต้องแยก 2 USD layer

URDF เก็บ **drive gain, damping, contact offset, friction, sensor attachment**
ของ Isaac ไม่ได้

ถ้าแก้ค่าพวกนี้ลงใน USD ที่ import มาโดยตรง แล้ววันหนึ่ง CAD เปลี่ยนแล้ว regenerate
→ tuning ทั้งหมดหาย

การแยก layer ทำให้ **regenerate `rover_base.usd` ได้ตลอดเวลาโดยไม่แตะ tuning**

| ไฟล์ | สถานะ | เจ้าของ |
|---|---|---|
| `rover_base.usd` | generated, **gitignored** | URDF importer |
| `rover.usd` | override layer, **commit** | คนปรับ physics ใน Isaac |

Friction ของล้อกับ heightfield เป็นค่าที่ tune ยากที่สุดของโปรเจกต์นี้ —
มันอยู่ใน `rover.usd` และเสียไปตอน regenerate ไม่ได้

---

## กฎการแก้ขนาด

เมื่อขนาดทางกายภาพเปลี่ยน ต้องทำครบทั้ง 3 ขั้นนี้ — ไม่ต้องรอ Fusion:

1. แก้ `cad/parameters/parameters.csv` โดยตรง แล้ว commit — มันคือต้นทางของ
   geometry (ดู [Pipeline](#pipeline) ด้านบน) **ไม่ใช่ export จาก Fusion**
2. รัน `tools/generate_sim_meshes.py` เพื่อ regenerate `cad/exports/meshes/`
   และ `cad/urdf/meshes/` — **ไม่ใช่ export mesh มือจาก Fusion**
3. Regenerate URDF → base USD (Isaac importer)

แล้วรัน:

```bash
pytest tests/unit/test_cad_config_sync.py       # จับ config/ ที่ยังไม่ตามขนาดใหม่
pytest tests/unit/test_generate_sim_meshes.py   # จับ mesh ที่ยังไม่ regenerate
pytest tests/unit/test_urdf_matches_cad.py      # จับ URDF ที่ยังอ้างขนาดเก่า
```

ทั้งสามข้อจับคนละจุดพัง เปลี่ยนขนาดครั้งเดียวอาจทำให้ข้อใดข้อหนึ่งพังโดยที่อีกสองข้อยังผ่าน
ต้องรันครบทั้งสาม — ไม่ใช่แค่ข้อแรก

ถ้า `test_cad_config_sync.py` fail แปลว่ามีค่าใน `config/` ที่ derived มาจาก CAD แล้วยังไม่ได้อัปเดต
ดูตาราง derived ใน [parameters/README.md](parameters/README.md)

**อย่าแก้ค่าใน `config/rover.yaml` เพื่อให้ test ผ่าน** ถ้าต้นเหตุคือ CAD เปลี่ยน —
ต้องตามให้ค่าใน config สะท้อนของจริง

### งานผลิต — แยกต่างหาก ไม่บล็อกงาน sim

STEP/STL งานผลิตเป็นคนละ track จาก 3 ขั้นข้างบน และตามทีหลังได้เสมอโดยไม่บล็อกใคร
(design §9.1) — sim ไม่ต้องรอ assembly

ขั้นตอนเมื่อแก้ assembly (เปิดตัวบน cloud ไม่ใช่ `.f3d` ใน repo):

1. แก้ผ่าน **user parameter** เท่านั้น — อย่าพิมพ์ตัวเลขลง sketch และอย่าใช้
   Move/Copy กับ body ทั้งสองอย่างตัดชิ้นนั้นขาดจาก `parameters.csv`
2. Export `cad/fusion/rover_base_v0.f3d` ทับ — **ขั้นนี้ลืมบ่อยที่สุด**
3. Export `cad/exports/step/` ชิ้นที่กระทบ
4. Export `cad/exports/stl/` เฉพาะชิ้นที่ต้องพิมพ์ใหม่

assembly เป็นเจ้าของ `fusion/`/`step/`/`stl/` เท่านั้น — ไม่ใช่ต้นทางของ
geometry และไม่มีอะไรใน sim ขึ้นกับมัน

---

## ⚠️ พารามิเตอร์ที่แก้แล้วกระทบมากกว่าที่คิด

rover มี coupling ระหว่าง CAD กับ software ที่ gantry ไม่มี

| แก้ค่านี้ | กระทบอะไรนอกจากรูปร่าง |
|---|---|
| `camera_front_tilt_deg` | **gain ของ row follower ใช้ไม่ได้** — มุมกำหนด lookahead distance |
| `camera_front_height_mm` | เหมือนกัน — ความสูงก็กำหนด lookahead |
| `wheel_diameter_mm` | `wheel_v_max_mm_s` เปลี่ยน → พิสัยของ `omega_max` เปลี่ยน → **invariant `drive` ทั้งสองข้อ** |
| `track_width_mm` | สูตร mixing เปลี่ยน → `config/drive_mixing_vectors.csv` ต้อง regenerate ทั้งตาราง |
| `body_width_mm` | **invariant ข้อ 5** (`clear_furrow > body_width + 2 × runaway_budget`) |
| `chassis_clearance_mm` | **invariant ข้อ 4** (`> soil_variation`) |
| `camera_down_height_mm` | coverage ของ corridor — ถ้าต่ำเกินจะเห็นไม่ครบร่อง |
| `chassis_plate_width_mm` | ถ้าเกิน track − wheel_width โครงชนล้อ — `test_the_chassis_plate_clears_the_inner_faces_of_the_wheels` |

`camera_front_tilt_deg` เป็นตัวที่เจ็บที่สุด เพราะ **ไม่มี test จับได้** —
`test_cad_config_sync.py` ตรวจว่าตัวเลขตรงกัน แต่ตรวจไม่ได้ว่า gain ยังเหมาะกับมุมใหม่
ต้องกลับไป tune ที่ V1 และ V4 ใหม่ทั้งคู่

(กล้องของ gantry มองตรงลงและอยู่กับที่ มุมไม่มีผลต่อ control เลย)

---

## Git LFS

ไฟล์ binary ในโฟลเดอร์นี้โตเร็วและ diff ไม่ได้ ควรใช้ Git LFS

```bash
git lfs install
git lfs track "*.f3d" "*.step" "*.stp" "*.stl" "*.usd" "*.usdc" "*.obj" "*.dae"
git add .gitattributes
```

ตั้งแต่ commit แรกที่มีไฟล์จริง — ย้ายทีหลังต้องเขียนประวัติใหม่ทั้ง repo

`parameters.csv` และ `.urdf` เป็น text **ไม่ต้องใส่ LFS** — ต้องการ diff ที่อ่านได้
เพราะมันคือที่ที่การเปลี่ยนขนาดจะปรากฏตอน review

---

## Boundary

✅ CAD เป็นเจ้าของ: track width, wheelbase, ขนาดล้อ, ความสูงท้องรถ, ความกว้างตัวถัง,
ตำแหน่งและมุมขายึดกล้อง, ตำแหน่งรูยึดมอเตอร์, mass / inertia

❌ CAD **ไม่** เป็นเจ้าของ: `v_max`, `omega_max`, timeout, gain, threshold,
`soil_variation_mm`, `runaway_budget_mm` — พวกนี้เป็น **operational** อยู่ใน `config/`

เส้นแบ่ง: *ถ้าวัดด้วยเวอร์เนียร์ได้ = CAD · ถ้าเปลี่ยนได้โดยไม่ต้องถอดสกรู = config*

### กรณีชายขอบ: `wheel_v_max_mm_s` และ `wheel_v_min_mm_s`

สองค่านี้ไม่ใช่ทั้ง CAD แท้และ config แท้:

```text
wheel_v_max_mm_s = (motor_rpm / 60) × pi × wheel_diameter_mm
                 = (25 / 60) × pi × 250
                 = 327 mm/s
```

`wheel_diameter_mm` เป็น CAD · `motor_rpm` เป็นสเปกของของที่ซื้อ (BOM)
ค่าผลลัพธ์อยู่ใน `config/rover.yaml` พร้อม comment ชี้ทั้งสองต้นทาง

`wheel_v_min_mm_s` (deadband) **วัดจากมอเตอร์จริงเท่านั้น** คำนวณไม่ได้ —
ค่า 51 ใน config เป็นค่าประมาณจาก 15% duty ต้องวัดจริงที่ V3

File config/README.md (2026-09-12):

# config

> อย่า hard-code parameter ใน source code

---

## Files

| File | Scope |
|---|---|
| `rover.yaml` | Rover geometry (derived: cad), drive limit, bed geometry |
| `safety.yaml` | Runaway budget, timeout, row-loss frames, E-stop |
| `perception.yaml` | ExG floor, confidence, loop rate, corridor, weed area |
| `control.yaml` | Row follower gain — **แยกตาม backend** |
| `simulation.yaml` | Physics/render rate, camera, soil, bed generator, randomization |
| `camera.yaml` | Front (ไม่ calibrate) + down (intrinsic, homography, **error budget**) |
| `development.yaml` | Backend selection, logging |
| `drive_mixing_vectors.csv` | Golden vector ของ skid-steer mixing (ใช้ร่วมกับ firmware) |

---

## rover.yaml

```yaml
rover:
  track_width_mm: 430          # derived: cad track_width
  wheelbase_mm: 400            # derived: cad wheelbase
  body_width_mm: 520           # derived: cad body_width  (รวมล้อ = track + wheel_width)
  wheel_diameter_mm: 250       # derived: cad wheel_diameter
  chassis_clearance_mm: 125    # derived: cad chassis_clearance

  drive:
    v_max_mm_s: 160
    omega_max_deg_s: 25
    wheel_v_max_mm_s: 327      # derived: cad wheel_diameter + มอเตอร์ 25 RPM (poc-v3.md)
    wheel_v_min_mm_s: 51       # deadband — ต้องวัดจริงที่ V3

bed:
  soil_variation_mm: 15
  row_spacing_mm: 750
  crop_foliage_half_width_mm: 30    # ประมาณ — ต้องวัดจาก asset พืชที่ V1
```

### `omega_max_deg_s` เป็น 25 — เลือกจากสมรรถนะการเลี้ยว ไม่ใช่จาก deadband โดยตรง

`omega_max = 25 deg/s` หมายถึงหมุน 180° ใน 7.2 วินาที ซึ่งเหมาะกับเครื่อง 35 kg —
skid steer ที่ track 430 mm บนยาง Ø250 เสียดสีด้านข้างกินแรงบิดจริง (design §6.1)
เลือกก่อนแล้วจึงบีบหน้าต่างความเร็วมอเตอร์ ไม่ใช่ไล่หาจากมอเตอร์ก่อน

```text
`omega_max_deg_s: 25` ไม่ใช่ค่าที่เลือกเพราะชอบ — differential ของล้อเป็นสัดส่วนกับ
track ซึ่งโตจาก 120 เป็น 430 (3.6 เท่า) ที่ 40 deg/s เดิม ล้อข้างในจะได้
160 - 150 = 10 mm/s ซึ่งอยู่ใต้ deadband: ล้อหยุดนิ่งขณะที่ ESP32 ยังคิดว่ากำลังขับ
และรถเลี้ยวแรงกว่าที่สั่งโดยไม่มีอะไรส่งสัญญาณ

ที่ omega_max = 25:  differential = 93.8 mm/s → v_left = 160 - 93.8 = 66.2 mm/s  ✓ เหนือ 51 (margin 15.2)

เพดานจริงของ `omega_max` ที่ track 430 คือ **~29.0 deg/s** (ที่ 29.05° ค่า `v_left`
จะแตะ 51 พอดี) — เลือก 25 เพื่อให้มี margin ไม่ใช่เพราะ 25 เป็นค่าสูงสุดที่ทำได้
```

`v_max_mm_s: 160` เพดานจาก runaway budget คือ 200 (60 mm / 0.3 s) เลือก 160
เพราะมันดัน margin ของ invariant ข้อ 7 จาก 5.2 เป็น 15.2 mm/s ซึ่งเป็นข้อเดียว
ที่พึ่งค่าที่ยังไม่ได้วัด

`wheel_v_min_mm_s: 51` ถูกเก็บไว้เท่าเดิมโดยเจตนาแม้เปลี่ยนมอเตอร์ทั้งชั้น — 15%
duty ของ 327 ให้ 49 แต่ค่าที่เข้มกว่าคือค่าที่เก็บ เหมือนที่ BOM รุ่นก่อนทำไว้ เกียร์
planetary มีชั้นเฟืองมาก stiction สูง deadband จริงอาจสูงกว่า 15% ไม่ใช่ต่ำกว่า
เก็บ 51 ไว้จนกว่าจะวัดจริงที่ V3

ถ้าล้อข้างในอยู่ใน deadband มันจะ**หยุดหมุนขณะที่ ESP32 คิดว่ากำลังสั่งให้หมุน** —
rover จะเลี้ยวแรงกว่าที่สั่งโดยไม่มีสัญญาณบอก

### `row_spacing_mm` ไม่ใช่ความกว้างที่ rover วิ่งได้

```text
clear_furrow = row_spacing − 2 × crop_foliage_half_width = 750 − 60 = 690 mm
```

invariant ทุกข้อที่เกี่ยวกับช่องว่างด้านข้างใช้ `clear_furrow` **ไม่ใช่** `row_spacing`

### `crop_foliage_half_width_mm` คือ margin ของ invariant ข้อ 5 ทั้งก้อน

```text
row_spacing 750 ผ่านตราบใดที่ crop_foliage_half_width < 55 mm
ถ้า V1 วัดได้ 55+ → row_spacing ต้องเป็น 800+

นี่ไม่ใช่การแก้ config — เป็นข้อจำกัดว่าแปลงต้องปลูกห่างเท่าไร
```

รถกว้างรวมล้อ 520 mm บังคับว่าแถวต้องห่างเท่าไร แถว 750 mm ที่ใบพืชกว้างข้างละ
30 mm แปลว่าพืชระยะต้นอ่อน ซึ่งเป็นช่วงที่กำจัดวัชพืชอยู่แล้ว จึงสอดคล้องกัน
แต่ margin ทั้งหมดของ invariant ข้อ 5 (50 mm) ถูกใช้จ่ายไปกับค่านี้ที่ยังไม่ได้วัด

---

## safety.yaml

```yaml
safety:
  runaway_budget_mm: 60
  row_loss_frames: 3
  command_timeout_ms: 300
  link_lost_ms: 500
  ack_timeout_ms: 200
```

**ไม่มี `enable_estop`** โดยเจตนา — E-stop ตัด motor rail ทางไฟ (§11.4)
config key ปิดรีเลย์ไม่ได้ `false` จึงแปลได้อย่างเดียวว่า "ให้ software เมินสาย sense"
ซึ่งคือ rover ที่หยุดไปแล้วแต่ state machine ยังคิดว่ากำลังวิ่งอยู่

§5.6 บอกว่าแต่ละชั้นต้องทำงานได้โดยไม่พึ่งชั้นบน — ชั้น software จึงไม่ใช่ชั้นที่
ปิดแล้วยังเรียกว่า safe ได้ สาย sense อ่านโดย `controller/safety/emergency_stop.py` เสมอ

`runaway_budget_mm` คือ **ระยะที่ยอมให้ rover วิ่งต่อหลังเสียการควบคุม**
MVP ไม่มี bumper switch ค่านี้จึงเป็นตัวชดเชยหลัก
ต้องเล็กกว่าระยะจากกันชนหน้า rover ถึงขอบแปลงและถึงต้นพืชที่ใกล้สุด —
**ต้องวัดจากแปลงจริงแล้วบันทึก** ไม่ใช่เดา

`link_lost_ms (500) > command_timeout_ms (300)` **โดยเจตนา** — ESP32 ต้องดับมอเตอร์
ก่อนที่ Pi จะประกาศ error เพื่อให้ลำดับเหตุการณ์ใน log อ่านได้ว่าอะไรเกิดก่อน
ถ้ากลับกัน Pi จะเข้า `ERROR` ขณะที่ล้อยังหมุนอยู่ 200 ms

`ack_timeout_ms` คือ deadline ของ Rule 4 ใน [protocol/messages.md](../protocol/messages.md) —
discrete command (`stop` · `emergency_stop` · `reset`) ที่ไม่ได้ `ack` ภายในเวลานี้
→ `ERROR` code `communication_lost` พร้อม `id` ของ command นั้น

**ไม่ใช้กับ `drive`** ซึ่งเป็น streaming — เฟรมที่ตกหนึ่งเฟรมต้องไม่กลายเป็น error

เป็นคนละเรื่องกับอีกสองค่าและต้องแยกกัน: `command_timeout_ms` คือ deadline ที่ **ESP32**
รอ `drive` ตัวถัดไป · `link_lost_ms` คือเพดานของ `link_age_ms` ฝั่ง **Pi**
ทั้งสามเรียงกันเป็น 200 < 300 < 500 เพื่อให้ลำดับใน log อ่านได้ว่าอะไรเกิดก่อน

---

## perception.yaml

```yaml
perception:
  loop_hz: 10                  # front camera / control loop
  camera_timeout_ms: 300

  exg:
    exg_floor: 12              # ต้อง tune ด้วยมือ — ดูหมายเหตุ

  row_estimator:
    conf_min: 0.25             # valley prominence ขั้นต่ำ
    green_fraction_row_end: 0.10   # สมมติฐาน — ต้องวัดที่ V1
    front_downscale: [320, 240]

  weed_detector:
    max_lateral_error_mm: 40   # สมมติฐาน — ต้องวัดที่ V1
    min_weed_area_mm2: 60
    down_rate_hz: 2
```

### `exg_floor` เป็นค่าเดียวใน pipeline ที่ต้อง tune ด้วยมือ

ExG threshold ใช้ **Otsu ต่อเฟรม** ไม่ใช่ค่าคงที่ เพราะสีดินเปลี่ยนตามความชื้น

แต่ Otsu มีจุดตาย: **เมื่อไม่มีสีเขียวในเฟรมเลย มันจะแบ่ง noise ออกเป็นสองกอง**
แล้วคืน mask ที่ดูเหมือนมีพืช ทำให้ `row_end` ตรวจไม่เจอ

`exg_floor` เป็นพื้นที่กันข้อนี้ — ต้องมี unit test ป้อนภาพดินเปล่า
ยืนยันว่าได้ mask ว่าง

### `green_fraction_row_end` แยก `row_end` ออกจาก `row_lost`

ทั้งสองกรณีมาถึงเหมือนกันเป๊ะ — estimate invalid ติดกัน `row_loss_frames` เฟรม
ตัวแยกมีตัวเดียวคือ `green_fraction` ของเฟรมที่ทำให้ watchdog trip (§5.4):

```text
green_fraction <  0.10    เขียวหมดจากเฟรม      สุดร่อง   → STOPPED(row_end_suspected)
green_fraction >= 0.10    ยังเห็นเขียวแต่ไม่มีเส้น  nav พลาด  → ERROR(row_lost)
```

อยู่ใน `perception.yaml` ไม่ใช่ `safety.yaml` เพราะมันเป็นสมบัติของ **mask ที่ ExG ผลิต**
ไม่ใช่ของ watchdog — ถ้า `exg_floor` เปลี่ยน หรือ asset พืชเปลี่ยน ค่านี้ต้องขยับตาม
การวางไว้ข้าง `exg_floor` ทำให้คนที่ tune ExG เห็นว่ามีค่านี้ผูกอยู่

⚠️ **`0.10` ยังไม่ถูก validate** — เป็นสมมติฐานแบบเดียวกับ `max_lateral_error_mm`
V0 พิสูจน์ได้แค่ว่า *ตรรกะ* เปรียบเทียบถูกและ watchdog นับถูก เพราะ harness
ไม่มี pixel และไม่มีต้นพืช การยืนยันว่าเส้นนี้แยกช่องว่างกลางแถวออกจากสุดร่อง
ได้จริงต้องใช้ภาพ render — คือ `crop_gap_midrow.yaml` กับ `row_end.yaml` ที่ V1
**ต้องผ่านทั้งคู่** ผ่านข้างเดียวแปลว่าตั้งเอาใจข้างเดียว

กรณีเท่ากับ threshold พอดีนับเป็น `row_lost` — nav ที่พลาดแล้วถูกบันทึกว่าจบร่องปกติ
คือทิศที่กลบปัญหา ส่วนทิศกลับกันแค่เรียกคนมาดู

### `max_lateral_error_mm` กำหนดความกว้าง corridor

```text
corridor = clear_furrow − 2 × max_lateral_error_mm = 690 − 80 = 610 mm
```

เป็นแถบที่รับประกันว่าอยู่ในร่องแม้ rover เบี่ยงเต็มพิสัย — สีเขียวในแถบนี้
จึงเป็นวัชพืชได้โดยไม่ต้องรู้ว่าแถวอยู่ไหน

`40` เป็น **สมมติฐาน** ต้องวัดค่าจริงที่ V1 ถ้าเกิน corridor จะแคบลงและ recall ตก

---

## control.yaml

```yaml
row_follower:
  v_mm_s: 160
  omega_max_deg_s: 25

  gains:
    fake:  {k_lat: 45.0, k_head: 25.0}
    isaac: {k_lat: 45.0, k_head: 25.0}
    esp32: {k_lat: null, k_head: null}    # ยังไม่ tune บนของจริง
```

### `null` เป็น guard ไม่ใช่ค่าที่ถูกลืม

ถ้า `backend: esp32` แล้ว gain เป็น `null` → fail ตอน startup ด้วย `config_invalid`

เหตุผล: slip ของ skid-steer บนดินจริงไม่เท่ากับใน sim การปล่อยให้ค่า sim
ถูกใช้เป็น default บนของจริงคือ rover ที่แกว่งเข้าหาต้นพืชโดยไม่มีใครรู้ว่าทำไม
**การบังคับให้ประกาศว่า "ยังไม่ได้ tune" ถูกกว่าการค้นหาสาเหตุในแปลง**

### ⚠️ gain ผูกกับ `camera_front_tilt_deg`

มุมก้มของกล้องหน้ากำหนดว่า `valley_far` อยู่ห่างไปข้างหน้าเท่าไร ซึ่งคือ
**lookahead distance** ถ้าขยับขายึดกล้อง gain ที่ tune ไว้ใช้ไม่ได้

นี่เป็น coupling ระหว่าง CAD กับ control ที่ gantry ไม่มี (กล้อง gantry มองตรงลง
มุมไม่มีผลต่อ control) — ดู [../cad/parameters/README.md](../cad/parameters/README.md)

### หน่วยของ gain

`RowEstimate` ไม่มีหน่วย mm หรือ deg (กล้องหน้าไม่ calibrate) gain จึงมีหน่วย
`(deg/s) / unitless` และ **ต้อง tune** ไม่มีสูตรคำนวณจากเรขาคณิต

---

## simulation.yaml

```yaml
simulation:

  physics_hz: 60
  render_hz: 30

  camera:
    front: { width: 640, height: 480 }
    down:  { width: 1280, height: 720 }

  soil:
    variation_mm: 15
    resolution_mm: 10

  environment:
    bed_length_mm: 2000
    crop_rows: 3
    crop_spacing_mm: 80
    row_spacing_mm: 750
    weed_count: 20

  randomization:
    enabled: true
    row_jitter_mm: 15
    row_angle_deg: 3
    row_curvature_mm: 40
    crop_gap_probability: 0.08
```

`soil.variation_mm` ต้องตรงกับ `bed.soil_variation_mm` ใน `rover.yaml` —
ถ้าไม่ตรง simulation จะสร้างดินที่ขัดกับ geometry invariant โดยที่ invariant check ผ่าน
ข้อนี้เป็น **invariant ข้อที่ 9** ที่บังคับตอน startup ไม่ใช่แค่คำแนะนำ

`row_curvature_mm` และ `crop_gap_probability` **ต้องไม่เป็น 0** ในการทดสอบปกติ:

| Parameter = 0 แล้วเกิดอะไร |
|---|
| `row_curvature_mm: 0` → ร่องตรงเป๊ะ `RowFollower` ผ่านได้ด้วย `gain = 0` เราจะไม่รู้เลยว่ามัน track ได้จริงไหม |
| `crop_gap_probability: 0` → ไม่มีต้นหาย heuristic แยก `row_end`/`row_lost` จะไม่ถูกทดสอบที่จุดที่มันพังจริง |

---

## camera.yaml

```yaml
cameras:

  front:
    calibrated: false          # โดยเจตนา — row following ใช้แค่มุม/offset ในภาพ
    device: /dev/video0

  down:
    device: /dev/video1
    intrinsic: { fx: null, fy: null, cx: null, cy: null }
    distortion: null
    homography: null           # เติมจาก tools/calibration/
    error_budget_mm: 20        # target — ต้องวัดจริงแล้วบันทึกค่าที่วัดได้
```

### กล้องหน้าไม่ calibrate โดยเจตนา

`RowEstimate` เป็นค่า image-space ล้วน (`lateral_err`, `heading_err` เป็น ratio
ใน `[-1, 1]`) และ `heading_err` คำนวณจากผลต่างของ valley สองระยะ
ซึ่ง **ไม่ต้องรู้ geometry กล้องเลย**

ผลคืองาน calibration ของ MVP เบากว่า design gantry — เหลือกล้องเดียว

### `error_budget_mm: 20` ผ่อนจาก 8 ของ design gantry

ผ่อนได้เพราะ **MVP ไม่มีอะไรกระทำต่อตำแหน่ง** — ไม่มี tool ที่ต้องเล็ง
ตัวเลข mm ใช้แค่บันทึกขนาด/ตำแหน่งคร่าว ๆ ใน log

แต่ยัง **ต้องทำ** homography ตอนนี้ ไม่เลื่อนทั้งหมด — เพื่อรู้ตัวเลข error budget จริง
บนดิน ±15 mm **ก่อน** ออกแบบ tool ที่ M3 ไม่ใช่หลังจากนั้น

---

## development.yaml

```yaml
backend: isaac

logging:
  level: INFO
  weed_log_path: logs/weeds.jsonl
```

---

## Backend Switching

เปลี่ยน backend โดยไม่แก้ code:

| Use case | Setting |
|---|---|
| Unit test + closed-loop row following (ไม่ต้องเปิด Isaac) | `backend: fake` |
| Simulation | `backend: isaac` |
| Hardware | `backend: esp32` |

---

## Startup Invariants

ตรวจที่ `controller/startup_checks.py` — **ทุกข้อ fail = ไม่ start**
พร้อมบอกค่าที่ขัดกันเป็นตัวเลข ไม่ใช่ warning

```text
safety      v_max × command_timeout/1000        <= runaway_budget         48 <= 60   ok
safety      v_max × row_loss_frames/loop_hz     <= runaway_budget         48 <= 60   ok
geometry    wheel_diameter        >= 4 × soil_variation                  250 >= 60   ok
geometry    chassis_clearance     >  soil_variation                      125 >  15   ok
geometry    clear_furrow          >  body_width + 2 × runaway_budget     690 > 640   ok
drive       v + omega_max_rad × track/2  <= wheel_v_max               253.8 <= 327  ok
drive       v − omega_max_rad × track/2  >= wheel_v_min                66.2 >=  51
config      gains[backend] ไม่เป็น null
consistency simulation.soil.variation_mm == bed.soil_variation_mm

โดย clear_furrow = row_spacing − 2 × crop_foliage_half_width
```

ข้อ geometry ทั้งสองข้อเคยเป็นข้อที่คับที่สุดของเครื่องเดิม — ล้อ Ø250 และ
ท้องรถ 125 mm ปลดทั้งคู่ทิ้ง (margin 190 mm และ 110 mm ตามลำดับ)
**`clear_furrow > body_width + 2 × runaway_budget` กลายเป็นข้อที่คับที่สุดแทน**
(margin 50 mm) — ดู [§`crop_foliage_half_width_mm`](#crop_foliage_half_width_mm-คือ-margin-ของ-invariant-ข้อ-5-ทั้งก้อน)

### ข้อ `drive` ตัวล่างมี margin 15.2 mm/s

`wheel_v_min_mm_s = 51` เป็นค่าประมาณจาก 15% duty **ยังไม่ได้วัดจากมอเตอร์จริง**

ถ้าวัดจริงที่ V3 ได้เกิน **66.2 mm/s** → **ต้องลด `omega_max` ลงอีก**
**ห้ามลด `wheel_v_min` เพื่อให้ผ่าน** — ค่านั้นเป็นคุณสมบัติของมอเตอร์ ไม่ใช่ค่าที่เราเลือก

### ตัวเลขที่ invariant จับได้ตอนเขียน spec

ชุดนี้ถูกแก้เพราะลองคูณเลขแล้วขัดกันเอง ไม่ใช่เพราะคิดว่าจะตั้งผิด:

| แก้อะไร | จาก → เป็น | invariant ที่จับได้ |
|---|---|---|
| `row_spacing_mm` | 250 → 350 → **750** | `clear_furrow > body_width + 2 × runaway_budget` — 350 มาจากรอบ MVP เดิม (rover 145 mm), 750 มาจากรอบ scale-up นี้ (rover 520 mm) |
| `omega_max_deg_s` | 60 → 40 | `v − omega_max_rad × track/2 >= wheel_v_min` — ที่รอบ MVP เดิม (`track_width 120`) ปัจจุบันคือ **25** ที่ `track_width 430` (ดูเหตุผลข้างบน) |
| นิยามข้อ 5 | `row_spacing` → `clear_furrow` | ใบพืชกินร่องข้างละ 30 mm ที่สูตรเดิมมองไม่เห็น |
| `track_width_mm` | 140 → 120 | `body_width` ต้องเป็นความกว้าง**รวมล้อ** (`track + wheel_width`) ไม่ใช่แค่แชสซี — ที่ 140 เหลือ margin แค่ 4 mm (ประวัติของเครื่อง 145 mm เดิม ก่อนรอบ scale-up นี้ที่ `track_width` เป็น 430) |

---

## Derived Values

ค่าที่มี comment `# derived: cad ...` **ห้ามแก้เพื่อให้ test ผ่าน** —
ต้นทางคือ `cad/parameters/parameters.csv` ถ้า test fail แปลว่า CAD เปลี่ยน
แล้ว config ยังตามไม่ทัน

```bash
pytest tests/unit/test_cad_config_sync.py
```

ตารางความสัมพันธ์ทั้งหมด: [../cad/parameters/README.md](../cad/parameters/README.md#derived-values--ค่าที่ไหลจาก-cad-ไป-config)

เส้นแบ่งความเป็นเจ้าของ:

| | เจ้าของ |
|---|---|
| วัดด้วยเวอร์เนียร์ได้ (track width, ล้อ, chassis, ขายึดกล้อง) | **CAD** |
| เปลี่ยนได้โดยไม่ต้องถอดสกรู (v_max, timeout, gain, threshold) | **config** |

### ค่าที่ต้อง **วัดจริง** แล้วเขียนกลับ

ค่าเหล่านี้ตั้งไว้เป็นค่าประมาณที่สอดคล้องกัน **ไม่ใช่ค่าที่วัดแล้ว**

| ค่า | วัดที่ | ผลถ้าผิด |
|---|---|---|
| `crop_foliage_half_width_mm` | V1 (asset พืช) | กระทบ invariant ข้อ 5 **และ** corridor พร้อมกัน |
| `max_lateral_error_mm` | V1 | corridor แคบ/กว้างผิด recall เพี้ยน |
| `wheel_v_min_mm_s` | V3 (มอเตอร์จริง) | `omega_max` สูงเกิน ล้อข้างในหยุดเงียบ |
| `runaway_budget_mm` | V4 (แปลงจริง) | ค่าความปลอดภัยหลักของ MVP |
| `error_budget_mm` | V4 (calibrate) | ตัวเลขใน weed log ไม่มีความหมาย |
| `gains.esp32` | V4 (tune) | ค้างเป็น `null` = ไม่ start (ตั้งใจ) |

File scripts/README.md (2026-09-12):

# scripts

Entry point สำหรับ run และ flash

| Script | Purpose |
|---|---|
| `run_sim.sh` | เปิด Isaac Sim + โหลด scene (`sim/isaac/app.py`) |
| `run_controller.sh` | รัน Controller ตาม backend ใน `config/development.yaml` |
| `run_fake_loop.sh` | Closed-loop row following ด้วย `FakeRover` — **ไม่ต้องมี Isaac** |
| `run_all.sh` | เปิด Simulation + Bridge + Controller พร้อมกัน (SIL) |
| `flash_esp32.sh` | PlatformIO build + upload firmware ไป ESP32 |
| `import_urdf.sh` | Import `cad/urdf/weeding_rover.urdf` → `rover_base.usd` (generated) |

---

## Typical Workflows

### V0 — logic only, ไม่ต้องมีกราฟิก

```bash
./scripts/run_fake_loop.sh --offset-mm 60 --heading-deg 15 --seconds 3
```

พิมพ์ trace ของ `lateral_err` และ `min_clearance_mm` ออกมา ใช้ tune gain
ก่อนแตะ Isaac เลย — ตัวเดียวกับที่ `tests/unit/` เรียกใช้

```bash
# config/development.yaml → backend: fake
./scripts/run_controller.sh
```

### V1/V2 — Software-in-the-Loop

```bash
# config/development.yaml → backend: isaac
./scripts/run_all.sh
```

### V3 — Hardware-in-the-Loop

```bash
./scripts/flash_esp32.sh
# config/development.yaml → backend: esp32
./scripts/run_all.sh
```

⚠️ **ยกล้อลอยก่อน** — safety ทั้งสามชั้นต้องถูกทดสอบตอนที่การทดสอบล้มเหลว
แล้วไม่มีอะไรวิ่งหนี ดู [../docs/hardware.md](../docs/hardware.md#hardware-in-the-loop--ต้องล้อลอย)

### V4 — แปลงจริง

```bash
# ต้อง tune gains.esp32 ใน config/control.yaml ก่อน
# ถ้ายังเป็น null → startup จะ fail ด้วย config_invalid (ตั้งใจ)
./scripts/run_controller.sh
```

---

## Startup จะปฏิเสธ config ที่ขัดกัน

ทุก script ที่รัน controller เรียก `controller/startup_checks.py` ก่อน —
invariant 9 ข้อ fail ข้อใดก็ **ไม่ start** พร้อมบอกค่าที่ขัดกันเป็นตัวเลข

```text
config_invalid: clear_furrow (690 mm) must exceed
                body_width (520) + 2 × runaway_budget (60) = 640 mm
```

นี่ไม่ใช่ความรำคาญ — มันเป็นตัวแทนของ bumper switch ที่ MVP ไม่มี
ดู [../config/README.md](../config/README.md#startup-invariants)

---

## CAD → Simulation

หลังแก้ขนาดใน `cad/parameters/parameters.csv` และ regenerate mesh แล้ว:

```bash
./scripts/import_urdf.sh
pytest tests/unit/test_cad_config_sync.py
```

`import_urdf.sh` เขียนทับ `sim/isaac/robots/rover/rover_base.usd` เสมอ —
physics tuning อยู่ใน `rover.usd` ที่เป็น layer ทับ จึงไม่หาย

⚠️ ถ้าแก้ `camera_front_tilt_deg` หรือ `camera_front_height_mm`
**gain ของ row follower ใช้ไม่ได้แล้ว** — มุมและความสูงกำหนด lookahead distance
ต้อง tune ใหม่ ไม่ใช่แค่ regenerate USD

ดู [../cad/README.md](../cad/README.md#pipeline)

---

## Firmware Test บน Host

ไม่ต้องมีบอร์ด:

```bash
pio test -e native -d firmware/esp32
```

ทดสอบ skid-steer mixing เทียบ [`config/drive_mixing_vectors.csv`](../config/drive_mixing_vectors.csv)
ตารางเดียวกับที่ Python ใช้ — ถ้าตัวใดตัวหนึ่ง fail แปลว่า implementation
สองภาษาเพี้ยนจากกัน

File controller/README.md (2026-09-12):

# controller

**Robot Brain** ของระบบ

---

## Responsibility

- Workflow
- State machine
- Row following
- Safety logic
- Startup invariant validation
- Timeout
- Fault management

Controller ต้องไม่รู้ว่ากำลังควบคุม Simulation หรือ Hardware จริง —
คุยผ่าน `Rover` และ `CameraSet` interface เท่านั้น

---

## Layout

```text
controller/
├── main.py                     # startup: load config → validate → select backend → run
├── startup_checks.py           # invariant 9 ข้อ — fail = ไม่ start
│
├── rover/
│   ├── base.py                 # Rover Protocol (the contract)
│   ├── isaac_rover.py          # → sim/isaac/adapters/
│   ├── esp32_rover.py          # → bridge/
│   ├── fake_rover.py           # kinematic-only, integrate (v, omega) → pose ภายใน
│   └── mixing.py               # skid-steer mixing + saturation (scale ไม่ clip)
│
├── motion/
│   ├── row_follower.py         # RowEstimate → (v, omega)   pure function
│   └── limits.py               # clamp v / omega ตาม config
│
├── workflow/
│   ├── state_machine.py        # RoverState transitions
│   └── row_run.py              # ลูป: estimate → follow → drive → log
│
└── safety/
    ├── runaway.py              # row-loss watchdog
    ├── link_monitor.py         # link_age_ms → link_lost
    ├── emergency_stop.py
    └── fault_manager.py
```

---

## Rover Interface

```python
from typing import Protocol

class Rover(Protocol):

    def drive(self, v_mm_s: float, omega_deg_s: float) -> None: ...

    def stop(self) -> None: ...

    # {"commanded": {"v_mm_s": float, "omega_deg_s": float},
    #  "estop": bool, "link_age_ms": int}
    def get_drive_state(self) -> dict: ...

    def emergency_stop(self) -> None: ...
```

`get_drive_state()` **ไม่มี field `measured` โดยเจตนา** — ไม่มี encoder จึงไม่มีใคร
รู้ว่าล้อหมุนจริงเท่าไร การซ้อนใต้ `commanded` ทำให้ call site อ่านออกว่าเป็น echo
ของคำสั่ง ไม่ใช่ feedback

ทุก backend ต้องคืน **key ชุดเดียวกันเป๊ะ** — มี test บังคับข้อนี้

Backend เลือกที่ startup เท่านั้น:

```python
if config.backend == "isaac":
    rover = IsaacRover()

elif config.backend == "esp32":
    rover = Esp32Rover()

else:
    rover = FakeRover()
```

---

## `row_follower.py` — pure function

```python
class RowFollower:
    def __init__(self, k_lat: float, k_head: float,
                 v_mm_s: float, omega_max_deg_s: float): ...

    def step(self, est: RowEstimate) -> tuple[float, float]:
        """→ (v_mm_s, omega_deg_s)"""
```

```python
omega = -(k_lat * est.lateral_err + k_head * est.heading_err)
omega = clamp(omega, -omega_max, +omega_max)
return (v_mm_s, omega)
```

`RowFollower` **ไม่รู้จัก camera และไม่รู้จัก rover** — รับ `RowEstimate` คืน tuple
เท่านั้น ทำให้ test ได้ด้วยตัวเลขสังเคราะห์ ไม่ต้องมีภาพ ไม่ต้องเปิด Isaac:

```python
def test_row_right_of_center_turns_right():
    v, omega = follower.step(RowEstimate(valid=True, lateral_err=+0.5, ...))
    assert omega < 0
```

### ทำไม P ไม่ใช่ PID

`heading_err` คืออัตราการเปลี่ยนของ `lateral_err` ในเชิงเรขาคณิตอยู่แล้ว
`k_head` จึงทำหน้าที่เป็นเทิร์ม **damping** โดยไม่ต้องหาอนุพันธ์จากสัญญาณภาพที่มี noise

ไม่เอา integral เพราะ offset ค้างในร่องไม่คุ้มกับความเสี่ยง windup

ความเร็ว `v` คงที่ใน MVP — การลดความเร็วเมื่อเบี่ยงมากเป็น knob ที่เพิ่มภายหลังได้

### Gain ไม่โอนข้าม backend

`config/control.yaml` เก็บ gain แยกตาม backend และ `esp32` เป็น `null`
จนกว่าจะ tune บนของจริง — slip ของ skid-steer บนดินจริงไม่เท่ากับใน sim

---

## `mixing.py` — saturation ต้อง scale ไม่ clip

```python
v_left  = v - omega_rad * track_width_mm / 2
v_right = v + omega_rad * track_width_mm / 2
```

ถ้าล้อข้างใดเกิน `wheel_v_max_mm_s` → **ลดทั้งสองข้างตามอัตราส่วนเดิม**

การ clip ข้างเดียวจะเปลี่ยน `omega` ที่ได้จริงโดยเงียบ ซึ่งเป็นความผิดพลาด
ประเภทเดียวกับ deadband ที่ทำให้ต้องลด `omega_max` จาก 60 เป็น 40

สูตรนี้ถูก implement ซ้ำใน C++ ที่ firmware ทั้งสองต้องผ่าน
[`config/drive_mixing_vectors.csv`](../config/drive_mixing_vectors.csv) ตารางเดียวกัน

---

## State Machine

```python
class RoverState(Enum):
    BOOT = 1
    READY = 2
    DRIVING_ROW = 3
    STOPPED = 4      # จบ run ปกติ รอคน ack
    ERROR = 5
    ESTOP = 6
```

```text
BOOT ──validate ผ่าน──> READY ──start──> DRIVING_ROW ──row_end──> STOPPED ──ack──> READY
  │                                            │
  │ validate ไม่ผ่าน                             │ row_lost / link_lost / camera_timeout
  ▼                                            ▼
ERROR <───────────────────────────────────── ERROR ──ack──> READY

ESTOP  ◄── estop == true จากทุก state ── ปลดปุ่ม + ack ──> READY
```

MVP วิ่ง **ร่องเดียวแล้วหยุด** — การเลี้ยวเข้าร่องถัดไปต้องเลี้ยวโดยมองไม่เห็น
ร่องเป้าหมาย ซึ่งไม่มี odometry มารองรับ (→ M4)

### `row_end` กับ `row_lost` แยกด้วย `green_fraction`

| `green_fraction` ตอน invalid | ตีความ | ปลายทาง |
|---|---|---|
| ต่ำ — สีเขียวหมดจากเฟรม | สุดร่องแล้ว | `STOPPED(row_end_suspected)` |
| สูง — ยังเห็นเขียวแต่จับเส้นไม่ได้ | navigation พลาด | `ERROR(row_lost)` |

ชื่อ `row_end_suspected` เตือนว่านี่คือ **heuristic ไม่ใช่การวัด** — scenario test
`row_end.yaml` กับ `crop_gap_midrow.yaml` เป็นคู่ตรงข้ามที่ต้องผ่านทั้งคู่
ผ่านข้างเดียวแปลว่า threshold ตั้งเอาใจข้างเดียว

---

## Control Loop

```python
while state is DRIVING_ROW:
    est = row_estimator.estimate(cameras.front())    # 10 Hz
    if not est.valid:
        watchdog.tick(est)
        continue
    watchdog.reset()
    rover.drive(*follower.step(est))
    weed_log.maybe_record(cameras.down())            # 1-2 Hz นอก control path
```

`weed_log` อยู่ในลูปแต่ **ไม่อยู่ใน control path** — detection ช้าหรือพลาด
ต้องไม่ทำให้ rover เลี้ยวผิด rate แยกกันชัดเจน (front 10 Hz, down 1-2 Hz)

---

## Safety — 3 ชั้น 3 เจ้าของ

| กลไก | เจ้าของ | อยู่ที่ไหน |
|---|---|---|
| Command timeout | **ESP32 firmware** | `firmware/esp32/` |
| Row-loss watchdog | **controller** | `safety/runaway.py` |
| Latching E-stop | **hardware** | ตัด motor rail ทางไฟ |

**แต่ละชั้นทำงานได้โดยไม่ต้องพึ่งชั้นบน** — ถ้าชั้นใดพึ่งชั้นบน
มันไม่ใช่ safety layer มันคือ feature

Controller ครองแค่ชั้นกลาง และต้องเขียนโดยสมมติว่าอีกสองชั้นมีอยู่จริง —
ไม่ใช่พยายามทำงานแทนทั้งสามชั้น

### `command_timeout` ที่รายงานกลับมา

เมื่อ ESP32 รายงาน `command_timeout` แปลว่ามอเตอร์ถูกดับไปแล้ว
Controller ต้องถือว่า **rover หยุดแล้วจริง** เข้า `ERROR` และ **ห้าม resume เอง**
การส่ง `drive` ต่อทันทีหลังเห็น error นี้คือการทำให้ rover ออกตัวโดยไม่มีคนสั่ง

---

## Startup Validation

`main.py` เรียก `startup_checks.py` ก่อน start งานจริง — **9 ข้อ fail ข้อใดก็ไม่ start**

```text
safety      v_max × command_timeout/1000        <= runaway_budget
safety      v_max × row_loss_frames/loop_hz     <= runaway_budget
geometry    wheel_diameter        >= 4 × soil_variation
geometry    chassis_clearance     >  soil_variation
geometry    clear_furrow          >  body_width + 2 × runaway_budget
drive       v + omega_max_rad × track/2  <= wheel_v_max
drive       v − omega_max_rad × track/2  >= wheel_v_min
config      gains[backend] ไม่เป็น null
consistency simulation.soil.variation_mm == bed.soil_variation_mm
```

Error message ต้องบอก **ค่าที่ขัดกันเป็นตัวเลข** ไม่ใช่แค่ชื่อ invariant:

```text
config_invalid: clear_furrow (690 mm) must exceed
                body_width (520) + 2 × runaway_budget (60) = 640 mm
                → เพิ่ม row_spacing_mm หรือลด runaway_budget_mm
```

ค่าเต็มและที่มา: [../config/README.md](../config/README.md#startup-invariants)

---

## `FakeRover` ปิดลูปได้โดยไม่ต้องมีกราฟิก

```text
FakeRover        integrate (v, omega) → pose ภายใน    (kinematic only)
FakeRowSensor    pose + สมการเส้นร่อง → RowEstimate
RowFollower      RowEstimate → (v, omega)
                        └──> วนกลับเข้า FakeRover
```

```python
def test_converges_from_offset():
    sim = FakeLoop(row=straight_row(), start_offset_mm=60, start_heading_deg=15)
    sim.run(seconds=3.0)
    assert abs(sim.history[-1].lateral_err) < 0.1
    assert sim.min_clearance_mm > 0        # ไม่เบียดต้นพืชระหว่างทาง
```

ตอบคำถาม *"gain ชุดนี้ลู่เข้าไหม และแกว่งเกินร่องไหม"* ในหลักมิลลิวินาที อยู่ใน CI ได้
ก่อนแตะ Isaac เลย

### ⚠️ `FakeRover.pose` ต้องไม่หลุดออก interface

`FakeRover` มี pose ภายใน แต่ **ห้าม expose ผ่าน `get_drive_state()`**

ถ้าหลุดออกมา code ที่เขียนตอน V0 จะพึ่งพา pose แล้วพังทั้งหมดตอนเปลี่ยนเป็น
`esp32` ที่ไม่มี pose ให้ — และจะพังตอนที่ debug ยากที่สุด คือตอนอยู่ในแปลง

`FakeRowSensor` เข้าถึง pose ได้ (มันคือ test harness) แต่ `RowFollower`,
`state_machine` และทุกอย่างใน `workflow/` ห้าม

---

## Run

```bash
./scripts/run_controller.sh          # ตาม backend ใน config/development.yaml
./scripts/run_fake_loop.sh           # closed-loop V0 ไม่ต้องมี Isaac
```

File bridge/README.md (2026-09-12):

# bridge

เชื่อม Controller กับ ESP32 หรือ Simulation

Protocol contract: [../docs/protocol.md](../docs/protocol.md)

---

## Layout

```text
bridge/
├── main.py                 # bridge process entry point
├── serial_link.py          # Serial transport — JSON บรรทัดละ message
├── protocol.py             # encode / decode + id correlation (discrete เท่านั้น)
├── seq_tracker.py          # seq → sent_at  แล้วคำนวณ link_age_ms จาก last_seq
└── simulator.py            # ESP32 emulator สำหรับ integration test
```

ไม่มี `mqtt.py` — ดู [§Transport](#transport)

---

## Role

```text
Controller ──drive / stop / estop──> bridge ──serial──> ESP32 / Simulation
                                  <──rover_state / ack / error──
```

Bridge รับผิดชอบ **transport + encoding เท่านั้น** — ไม่มี business logic

---

## Transport

```text
Serial เท่านั้น
```

Pi กับ ESP32 อยู่บนบอร์ดเดียวกัน control loop ไม่ข้ามเครือข่าย

**MQTT ถูกตัดออกจาก MVP** — Wi-Fi ไม่อยู่ใน control path อีกแล้ว
log เขียนไฟล์บน Pi ดึงทีหลัง

ที่ **115200 baud** (11.5 KB/s) ใช้ ~30% ของ link:

```text
ขึ้น   drive       ~70 B × 10 Hz  =   700 B/s
ลง    rover_state ~140 B × 20 Hz = 2,800 B/s
```

มี headroom พอเพิ่ม loop rate เป็น 50 Hz หรือเปลี่ยน encoding เป็น
MessagePack / Protobuf ภายหลังได้ **โดยไม่เปลี่ยน Controller**

---

## Streaming กับ Discrete — สองเส้นทางใน `protocol.py`

| | Streaming | Discrete |
|---|---|---|
| Message | `drive` | `stop` · `emergency_stop` · `reset` |
| Correlation | `seq` → `seq_tracker.py` | `id` → pending table |
| ตกหล่นได้ | ได้ | ไม่ได้ |
| Timeout → ERROR | **ไม่** | ใช่ |

`protocol.py` เก็บ pending command table และ raise timeout **เฉพาะ discrete command**

ถ้าเอา `drive` เข้า pending table ด้วย เฟรมที่ตกหนึ่งเฟรมจะกลายเป็น `ERROR`
และ table จะโตขึ้น 10 entry ต่อวินาทีตลอดเวลา

---

## `seq_tracker.py` — วัด link age โดยไม่ต้องซิงก์นาฬิกา

```python
tracker.sent(seq)                       # จำเวลาส่ง
...
link_age_ms = tracker.age(state["last_seq"])
```

ไม่ต้องมี clock sync ระหว่าง Pi กับ ESP32 — Pi ใช้นาฬิกาตัวเองทั้งขาส่งและขาคำนวณ
ESP32 แค่ echo `seq` กลับมา

`link_age_ms` เป็นค่าเดียวใน `get_drive_state()` ที่ **วัดได้จริง** —
`commanded` เป็น echo ไม่ใช่ feedback

`seq_tracker` ต้องตัด entry เก่าทิ้ง ไม่งั้นจะเก็บ 10 entry ต่อวินาทีไปเรื่อย ๆ
เก็บย้อนหลังเท่าที่ `link_lost_ms` ต้องการก็พอ

---

## `simulator.py`

ESP32 emulator — ใช้ใน `tests/integration/` เพื่อทดสอบ

```text
Controller + Bridge + ESP32 Emulator
```

โดยไม่ต้องมี hardware หรือ Isaac Sim

Emulator ต้องเลียนพฤติกรรมที่ firmware จริงต้องมี ไม่ใช่แค่ตอบ ack:

```text
[ ] command timeout — ไม่ได้ drive เกิน command_timeout_ms → motors_enabled: false
[ ] latest-wins — ยัด drive หลายตัว ใช้ตัว seq สูงสุด
[ ] ทิ้ง seq ที่ย้อนหลัง
[ ] stop / emergency_stop override drive ในรอบเดียวกัน
[ ] ปฏิเสธ reset ขณะ estop sense ยัง active
[ ] uptime_ms ลดลงเมื่อจำลองการรีบูต
```

ถ้า emulator ตอบ ack ทุกอย่างแบบสุภาพ integration test จะผ่านทั้งหมด
แล้วไปพังที่ V3 ซึ่งเป็นจุดที่ debug แพงกว่ามาก

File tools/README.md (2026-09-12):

# tools

Utility ที่ไม่อยู่ใน runtime path ของหุ่นยนต์

| Directory | Purpose |
|---|---|
| `calibration/` | Capture calibration target, solve intrinsic + homography ของ **กล้องล่าง**, เขียนผลลง `config/camera.yaml` (กล้องหน้าไม่ calibrate) |
| `dataset/` | Export image + label จาก Isaac Sim (domain randomization) สำหรับเทรน weed detector |
| `visualization/` | Plot detection overlay, **valley histogram**, `lateral_err` trace, rover path, scenario result |

---

## Notes

- Tool ใน folder นี้ **ห้าม** ถูก import จาก `controller/` หรือ `perception/` runtime
- `dataset/` ใช้ ground truth จาก Isaac Sim ทำให้ได้ label ฟรี —
  ใช้คู่กับ `sim/isaac/environments/domain_randomization.py`
- Calibration procedure: [../docs/calibration.md](../docs/calibration.md)

## เครื่องมือที่ต้องมีตั้งแต่ V1

| เครื่องมือ | ทำไมจำเป็น |
|---|---|
| Plot **valley histogram** ต่อเฟรม | เป็นวิธีเดียวที่ debug `row_estimator` ได้เร็ว — เห็นทันทีว่าหุบหายไปที่เฟรมไหน |
| Plot `lateral_err` / `omega` เทียบเวลา | แยกให้ออกว่า gain สูงเกิน (แกว่ง) หรือ mechanical เพี้ยน (offset ค้าง) |
| Plot error map ของ homography ทั่วเฟรม | หาโซนที่ error เกิน budget ±20 mm |
| วัด `max_lateral_error` จาก log ของ run | เป็นค่าที่ corridor ของ weed detector พึ่งอยู่ — ต้องวัด ไม่ใช่เดา |

สองตัวแรกสำคัญกว่าที่คิด: `RowFollower` เป็น pure function ที่ test ได้ด้วยตัวเลข
แต่ **`row_estimator` ทำงานกับภาพจริง** และมันคือจุดที่ MVP จะพังจริง ๆ
ถ้าไม่มีเครื่องมือดู histogram จะเหลือแค่การเดาว่าทำไม `valid = False`

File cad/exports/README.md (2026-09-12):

# cad/exports

โฟลเดอร์นี้มีสองแหล่งที่มา และกฎคนละข้อ

| | ต้นฉบับ | แก้ยังไง |
|---|---|---|
| `meshes/` | `cad/parameters/parameters.csv` | รัน `python tools/generate_sim_meshes.py` — **ห้ามแก้ไฟล์ด้วยมือ** |
| `step/` · `stl/` | CAD assembly (`../fusion/` — ตัวจริงบน cloud) | แก้ assembly แล้ว export ทับ |

`meshes/` เป็น simplified visual + collision สำหรับ simulator เท่านั้น
`step/` และ `stl/` เป็น geometry สำหรับผลิต มาจาก CAD assembly — **ไม่ auto-update**
ต้อง export ทับเองทุกครั้งที่แก้ assembly ดู [../README.md](../README.md)

---

## Formats

| Folder | Format | ใช้ทำอะไร | ความละเอียด |
|---|---|---|---|
| `step/` | STEP (.step) | งานผลิต, ส่งร้าน, review ทางวิศวกรรม | เต็ม |
| `stl/` | STL (.stl) | 3D print แชสซี / bracket / ขายึดมอเตอร์ / เสากล้อง | สูง |
| `meshes/` | OBJ / STL | visual + collision ใน simulation | **simplified** |

---

## `meshes/` ต้อง simplified

Mesh สำหรับ sim ไม่ใช่ mesh สำหรับพิมพ์ — เอา CAD mesh เต็ม ๆ ไปใส่ Isaac
จะทำให้ physics ช้าลงมากโดยไม่ได้ความแม่นยำที่มีความหมาย

| ประเภท | เป้าหมาย |
|---|---|
| Visual mesh | พอสวย ลด triangle ให้มากที่สุดเท่าที่ยังดูรู้เรื่อง |
| Collision mesh | **convex hull หรือ primitive** ไม่ใช่ mesh ละเอียด |

Collision ของ rover เป็น **box สำหรับตัวถัง + cylinder สำหรับล้อ 4 ตัว** เท่านั้น —
ใช้ primitive เร็วกว่าและเสถียรกว่า mesh เสมอ

**ล้อต้องไม่ใช่ mesh** แม้จะมีดอกยางใน CAD — mesh ล้อบน heightfield สร้าง contact
point จำนวนมาก ทำให้ solver ช้าลงมากและไม่เสถียร โดยไม่ได้ความแม่นยำที่มีความหมาย
เพราะ grip จริงมาจาก friction coefficient ใน `rover.usd` ไม่ใช่รูปดอกยาง

**MVP นี้ไม่มีข้อยกเว้น** — design gantry ยกเว้นให้หัว tool ใช้ mesh ได้
เพราะรูปทรงหัว tool มีผลกับการสัมผัสดินจริง MVP ไม่มี tool จึงไม่มีชิ้นไหน
ที่ต้องการ collision mesh ละเอียด (ข้อยกเว้นนี้กลับมาที่ M3)

---

## Export Checklist

`parameters.csv` เป็นต้นทาง — ทุกอย่างตามหลังมัน ไม่ใช่ตามหลัง CAD assembly อีกต่อไป
สองงานนี้แยกกัน ทำคนละเวลาก็ได้:

เมื่อขนาดใน `cad/parameters/parameters.csv` เปลี่ยน (ทำก่อนเสมอ):

```text
[ ] แก้ cad/parameters/parameters.csv แล้ว commit
[ ] python tools/generate_sim_meshes.py         — regenerate meshes/ (ห้าม export มือ)
[ ] regenerate URDF → base USD
[ ] pytest tests/unit/test_cad_config_sync.py
[ ] pytest tests/unit/test_generate_sim_meshes.py
[ ] pytest tests/unit/test_urdf_matches_cad.py
```

งานผลิต — แยกต่างหาก ตามทีหลังได้โดยไม่บล็อกใคร
(เมื่อต้อง export `step/`/`stl/` ใหม่สำหรับผลิต):

```text
[ ] เปิด assembly บน cloud (ไม่ใช่ .f3d ใน repo) แก้ผ่าน user parameter เท่านั้น
[ ] fusion/  export .f3d ทับ — ลืมบ่อยที่สุด
[ ] step/    export ชิ้นที่กระทบ
[ ] stl/     export เฉพาะชิ้นที่ต้องพิมพ์ใหม่
```

**origin ของ mesh ต้องตรงกับ link frame ใน URDF** — สำหรับ `meshes/` ตอนนี้
`tools/generate_sim_meshes.py` เป็นคนรับประกันให้แล้ว (เขียน mesh ที่ origin เดียวกับ
link เสมอ เป็นเมตร จึงไม่มี scale factor และไม่มีขั้นตอนมือให้พลาด)
คำเตือนนี้ยังมีผลกับไฟล์ที่ export ด้วยมือจาก CAD เท่านั้น — เป็นความผิดพลาด
ที่พบบ่อยที่สุดของงานมือแบบนั้น และอาการคือชิ้นส่วนลอยหรือหมุนผิดจุดใน Isaac
ดู [../../hardware/mechanical/coordinate-frames.md](../../hardware/mechanical/coordinate-frames.md)

---

## Git LFS

ไฟล์ในโฟลเดอร์นี้ควรอยู่ใน LFS ทั้งหมด ดู [../README.md](../README.md#git-lfs)

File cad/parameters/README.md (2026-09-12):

# CAD Parameters

**ต้นทางของตัวเลขขนาดทุกตัว** อยู่ที่ `parameters.csv` — ไฟล์นั้นคือของจริง
ไม่ใช่ export จาก CAD

แก้ที่ `parameters.csv` แล้ว commit ทุกครั้งที่ขนาดเปลี่ยน CAD assembly ที่จะ
สร้างขึ้นภายหลังต้องผูก user parameter ตามไฟล์นั้น ไม่ใช่ทางกลับกัน

Rover Base V0 — 650 × 520 mm, ล้อ Ø250, 4WD skid steer, ~35 kg
Design: [`docs/superpowers/specs/2026-09-12-rover-base-v0-scale-up-design.md`](../../docs/superpowers/specs/2026-09-12-rover-base-v0-scale-up-design.md)

---

## Naming Convention

```text
<part>_<dimension>_<unit>

track_width_mm
wheel_diameter_mm
camera_front_tilt_deg
```

ลงท้ายด้วยหน่วยเสมอ — ป้องกันความผิดพลาด mm/cm และ deg/rad ที่หาไม่เจอ
จนกว่าจะสร้างของจริง

---

## Parameters

### Chassis

| Parameter | ค่า | ความหมาย |
|---|---|---|
| `body_length_mm` | 500 | ความยาวตัวถัง (ไม่รวมล้อ) |
| `chassis_plate_width_mm` | 340 | ความกว้างโครงช่วงล้อ (z 125–250, ระดับเดียวกับล้อ) ดูหมายเหตุ |
| `body_width_mm` | **520** | **ความกว้างรวมล้อ = จุดกว้างสุดของรถ** ดูหมายเหตุ |
| `body_height_mm` | 280 | ความสูงตัวถัง (ไม่รวม mast) |
| `chassis_clearance_mm` | 125 | จากพื้นถึงท้องรถ = รัศมีล้อพอดี |

### Drive

| Parameter | ค่า | ความหมาย |
|---|---|---|
| `track_width_mm` | 430 | ระยะกึ่งกลางล้อซ้ายถึงกึ่งกลางล้อขวา |
| `wheelbase_mm` | 400 | ระยะกึ่งกลางเพลาหน้าถึงกึ่งกลางเพลาหลัง |
| `wheel_diameter_mm` | 250 | เส้นผ่านศูนย์กลางล้อรวมยาง — ดู [`hardware/bom/poc-v3.md`](../../hardware/bom/poc-v3.md) |
| `wheel_width_mm` | 90 | ความกว้างหน้ายาง |
| `motor_mount_bolt_circle_mm` | 60 | bolt circle หน้าแปลนมอเตอร์ 4 × M5 |

ไม่มี belt / pulley / stepper — ขับตรงจากมอเตอร์เกียร์ที่เพลาล้อ

`motor_mount_bolt_circle_mm` แทนที่ `motor_mount_pitch_mm` เดิมทั้งตัว — มอเตอร์
planetary ชั้นนี้ยึดด้วย bolt circle บนหน้าแปลน ไม่ใช่รูคู่แบบ micro metal gearmotor
ของเครื่องเดิม พารามิเตอร์เก่าไม่มีอยู่ใน `parameters.csv` แล้ว (ดู git history
ของไฟล์นี้สำหรับค่าเดิม)

### Mast และกล้อง

| Parameter | ค่า | ความหมาย |
|---|---|---|
| `mast_diameter_mm` | 35 | ท่อ mast |
| `mast_height_mm` | 500 | ความสูง mast เหนือหลังคาตัวถัง |
| `camera_front_height_mm` | 850 | ความสูงเหนือ soil reference (ใน mast head) |
| `camera_front_tilt_deg` | 50 | มุมก้มจากแนวนอน |
| `camera_front_offset_x_mm` | 0 | mast อยู่กึ่งกลางตัวรถ |
| `camera_down_height_mm` | 850 | ความสูงเหนือ soil reference (ใน mast head เดียวกัน) |
| `camera_down_tilt_deg` | 0 | 0 = มองตรงลง |
| `camera_down_offset_x_mm` | 0 | อยู่กึ่งกลางตัวรถ |

ความสูงที่ได้: ท้องรถ 125 → หลังคาตัวถัง 405 (125 + 280) → หัว mast 905
(405 + 500) กล้องทั้งสองตัวอยู่ที่ 850 mm ซึ่งอยู่ใน mast head พอดี — คนละ
ตำแหน่งกับเวอร์ชันก่อน scale-up ที่กล้องหน้าอยู่บนตัวถัง (180 mm) และกล้องล่าง
แยกเสาของตัวเอง (220 mm) ตอนนี้ **กล้องทั้งสองตัวขึ้น mast เดียวกัน** เพราะล้อ
Ø250 บังพื้นที่มองตรงลงจนต้องยกกล้องล่างขึ้นไปพ้นล้อ (design §6.3)

`camera_down_tilt_deg = 0` ตั้งใจ — ยิ่งเอียงยิ่งทำให้ error จากดินไม่เรียบใหญ่ขึ้น
เหตุผลเดียวกับกล้องของ design gantry ดู
[../../docs/calibration.md](../../docs/calibration.md#soil-plane-error-budget)

---

## ความสัมพันธ์ที่ test บังคับ

สามค่านี้เป็น **ผลลัพธ์** ไม่ใช่ค่าที่เลือกอิสระ — `test_cad_config_sync.py`
บังคับความสัมพันธ์ไว้ ห้ามแก้ค่าใดค่าหนึ่งโดยไม่ตรวจอีกสองตัว

```text
overall_length_mm      = wheelbase_mm + wheel_diameter_mm
                        = 400 + 250 = 650

body_width_mm           = max(chassis_plate_width_mm, track_width_mm + wheel_width_mm)
                        = max(340, 430 + 90) = 520

chassis_plate_width_mm <= track_width_mm - wheel_width_mm
                        = 430 - 90 = 340
```

| Test | ตรวจอะไร |
|---|---|
| `test_overall_length_is_measured_across_the_wheels` | `overall_length_mm` วัดคร่อมล้อ ไม่ใช่แค่ตัวถัง |
| `test_body_width_is_the_widest_point_not_the_chassis_plate` | `body_width_mm` คือจุดกว้างสุด (รวมล้อ) |
| `test_the_chassis_plate_clears_the_inner_faces_of_the_wheels` | โครงช่วงล้อไม่ชนหน้าในล้อ |

---

## ⚠️ `body_width_mm` ต้องเป็นความกว้างรวมล้อ ไม่ใช่ความกว้างแชสซี

```text
body_width = max(chassis_plate_width, track_width + wheel_width)
           = max(340, 430 + 90)
           = 520 mm
```

**ส่วนที่ชนใบพืชคือล้อ ไม่ใช่ตัวถัง** — `body_width_mm` ต้องสะท้อนขอบล้อ
ไม่ใช่ขอบแชสซี ไม่งั้น invariant ข้อ 5 จะผ่านโดยที่ล้อยังเบียดใบพืชอยู่

> เวอร์ชันก่อน scale-up (รถ 145 mm) เคยลด `track_width` จาก 140 เป็น 120
> ด้วยเหตุผลเดียวกันนี้ — เรื่องนั้นเป็นประวัติของเครื่องคนละขนาด ดู git history
> ของไฟล์นี้ ไม่ใช่ข้อจำกัดของรถคันนี้

### แชสซี 340 mm ไม่ชนล้อ ตัวถัง 380 mm ยื่นคร่อมได้ (design §3.2)

```text
หน้าในล้อ  = track/2 − wheel_width/2 = 215 − 45 = ±170   →  ระยะห่าง 340 mm

   z=405  ┌──────────────────────────┐   body 500 × 380 × 280
          │                          │
   z=250  ├────┐                ┌────┤   ← หลังคาล้อ (wheel top)
(O)       │    │  frame 340 max │    │       (O)
   z=125  └────┘                └────┘   ← ท้องรถ / ระนาบเพลา
────────────────────────────────────────  พื้น
          ±170 หน้าในล้อ
```

โครงช่วงล้อ (`chassis_plate_width_mm`) อยู่ในช่วง z 125–250 mm ซึ่งเป็นระดับ
เดียวกับตัวล้อพอดี — กว้างเกิน 340 mm ตรงนี้คือชนหน้าในล้อ ตัวถังด้านบน
(z 250–405 mm) อยู่เหนือหลังคาล้อแล้ว จึงยื่นคร่อมได้ถึง 380 mm โดยไม่ชน

⚠️ **340 คือ "ค่าสูงสุด" ไม่ใช่ค่าที่มี clearance** — ที่ 340 โครงแตะหน้าในล้อพอดี
(±170 ทั้งคู่) ไม่เหลือช่องให้ค่าความคลาดเคลื่อน ±2 mm ที่ source spec section 16
ยอมให้ ตอนขึ้นรูปจริงควรใช้ **320** เพื่อให้เหลือข้างละ 10 mm ค่า 340
ในตารางเป็นค่า "ขอบเขต" ที่ test บังคับ ไม่ใช่ค่าที่แนะนำให้ตัดเหล็ก

---

## Coverage Checks — คำนวณได้ ต้องตรวจก่อนสั่งกล้อง

สองข้อนี้ **ไม่ใช่ startup invariant** (ค่า FOV ไม่อยู่ใน config) แต่ต้องตรวจ
ก่อนซื้อของ และวัดจริงที่ V1

### กล้องล่างต้องครอบ corridor + ขอบ

```text
กล้องล่างต้องครอบ corridor + ขอบ
  corridor              610 mm   (clear_furrow 690 − 2 × max_lateral_error 40)
  ต้องครอบ + ขอบข้างละ 20  650 mm
  HFOV ที่ต้องการ >= 2 × atan(325 / 850) = 41.9°   →  ต้องการ >= 45°
```

ต้องมีขอบ ไม่ใช่ครอบแค่ corridor พอดี — กฎ `touches_side_edge` ทำงานได้เฉพาะ
เมื่อใบพืชผล**แตะขอบเฟรมจริง** ถ้าเฟรมกว้างเท่า corridor พอดี ใบพืชผลจะไม่มีที่ยืน
แล้วจะถูกนับเป็นวัชพืช

เทียบกับของเดิมที่ต้องการ ≥ 60° — เลนส์**ธรรมดาลง** ไม่ใช่กว้างขึ้น เพราะระยะ
850 mm โตเร็วกว่าความกว้างที่ต้องครอบ (design §6.3)

### ต้องไม่มีช่องว่างระหว่างเฟรม

```text
ต้องไม่มีช่องว่างระหว่างเฟรม
  เซนเซอร์ down คือ 1280 × 720 (16:9) จาก config/simulation.yaml
  VFOV ที่ HFOV 45° = 2 × atan(tan(22.5°) × 720/1280) = 26.2°
  coverage ตามแนววิ่ง = 2 × 850 × tan(13.1°) ≈ 396 mm
  ระยะที่รถวิ่งต่อเฟรม = 160 / 2 = 80 mm
  396 > 80  ✓
```

⚠️ **396 mm ไม่ใช่ 527 mm** — design spec §6.3 คำนวณ coverage ตามแนววิ่งไว้ที่
527 mm โดยสมมติเซนเซอร์ 4:3 (`VFOV 34.5°` จากอัตราส่วนภาพ 4:3) แต่
`config/simulation.yaml` ระบุกล้อง down เป็น **1280 × 720 (16:9)** จริง ซึ่งให้
VFOV แคบกว่าที่ HFOV เดียวกัน (26.2° ไม่ใช่ 34.5°) coverage จึงเหลือ 396 mm
ไม่ใช่ 527 mm ตัวเลขในเอกสารนี้คือค่าที่ตรงกับเซนเซอร์จริง — **อย่าแก้กลับเป็น
527** ถึงแม้ design spec จะยังพิมพ์ 527 ไว้เป็นบันทึกประวัติ (spec ไม่แก้ย้อนหลัง)
396 ยังมากกว่าระยะวิ่งต่อเฟรม (80 mm) มาก จึงยังผ่านสบาย

### กล้องหน้า — lookahead

```text
กล้องหน้า — lookahead
  lookahead = 850 / tan(50°) = 713 mm  = 1.1 เท่าของความยาวรถ
  เวลาที่ได้ = 713 / 160 = 4.5 s
```

**ตัวเลขนี้คือสิ่งที่ gain ของ row follower ถูก tune กับมัน** เปลี่ยนความสูง
หรือมุม แล้ว gain ใช้ไม่ได้ — ไม่มี test จับได้ ต้อง tune ใหม่ที่ V1 และ V4
(lookahead ขยับจาก 180 mm เป็น 713 mm ในรอบ scale-up นี้ ดู `config/control.yaml`)

กล้องหน้า **ไม่ต้องมีข้อกำหนด FOV เป็นองศา** เพราะ `RowEstimate` เป็นค่า
image-space ล้วน ขอแค่เห็นแถวพืชสองข้างอยู่ในเฟรมที่ระยะ lookahead

---

## Derived Values — ค่าที่ไหลจาก CAD ไป config

นี่คือรายการที่ต้อง sync ทุกครั้งที่ CAD เปลี่ยน

| CAD parameter | → ปลายทาง | ความสัมพันธ์ |
|---|---|---|
| `track_width_mm` | `config/rover.yaml` `rover.track_width_mm` | เท่ากัน |
| `track_width_mm` | `cad/urdf` wheel joint origin Y | `± track_width/2` (เมตร) |
| `track_width_mm` | `config/drive_mixing_vectors.csv` | **ต้อง regenerate ทั้งตาราง** |
| `wheelbase_mm` | `config/rover.yaml` · `cad/urdf` joint origin X | `± wheelbase/2` (เมตร) |
| `wheelbase_mm` + `wheel_diameter_mm` | `overall_length_mm` (เอกสารนี้) | `wheelbase + wheel_diameter` — บังคับด้วย test |
| `wheel_diameter_mm` | `config/rover.yaml` · `cad/urdf` wheel radius | radius = `d/2` (เมตร) |
| `wheel_diameter_mm` + BOM `motor_rpm` ([`poc-v3.md`](../../hardware/bom/poc-v3.md)) | `config/rover.yaml` `wheel_v_max_mm_s` | `(rpm/60) × pi × d` |
| `body_width_mm` | `config/rover.yaml` `rover.body_width_mm` | เท่ากัน — **ใช้ใน invariant ข้อ 5** |
| `chassis_clearance_mm` | `config/rover.yaml` | เท่ากัน — **ใช้ใน invariant ข้อ 4** |
| `mast_height_mm` + `mast_diameter_mm` | `cad/urdf` mast collision cylinder | radius = `mast_diameter/2`, สูง = `mast_height`, จุดศูนย์กลางที่ z = `chassis_clearance + body_height + mast_height/2` |
| `camera_front_*` | `config/camera.yaml` extrinsic | ค่าเริ่มต้น (กล้องหน้าไม่ calibrate) |
| `camera_down_*` | `config/camera.yaml` extrinsic | ค่าเริ่มต้นก่อน calibrate |
| `camera_front_height_mm` + `tilt_deg` | `config/control.yaml` **gain** | **ไม่มีสูตร — ต้อง tune** |

### `wheel_v_max` ตรวจสอบได้

```text
wheel_v_max = (motor_rpm / 60) × pi × wheel_diameter_mm
            = (25 / 60) × 3.14159 × 250
            = 0.41667 × 785.4
            = 327.2 mm/s   →  config: wheel_v_max_mm_s: 327
```

`motor_rpm = 25` มาจาก [`hardware/bom/poc-v3.md`](../../hardware/bom/poc-v3.md)
(หน้าต่างความเร็วที่ใช้ได้คือ 19.4–33.7 RPM บีบจาก invariant ข้อ 6 และ 7) —
**ไม่ใช่จาก CAD** `test_the_bom_still_states_the_motor_speed` และ
`test_wheel_v_max_follows_from_wheel_diameter_and_motor_rpm` บังคับทั้งค่าและสูตรนี้

### Startup invariants ที่ค่าจาก CAD เข้าไปเกี่ยวข้อง (design §7)

```text
geometry  wheel_diameter        >= 4 × soil_variation                  250 >= 60   ok  margin 190 mm
geometry  chassis_clearance     >  soil_variation                      125 >  15   ok  margin 110 mm
geometry  clear_furrow          >  body_width + 2 × runaway_budget     690 > 640   ok  margin  50 mm
drive     v + omega_max_rad × track/2  <= wheel_v_max                253.8 <= 327  ok  margin  73.2 mm/s
drive     v − omega_max_rad × track/2  >= wheel_v_min                 66.2 >=  51  ok  margin  15.2 mm/s
```

ข้อ geometry ทั้งสองข้อมี margin กว้างขึ้นมาก (190 mm, 110 mm) — ล้อ Ø250 และ
ท้องรถ 125 mm ปลดข้อจำกัดที่เคยคับที่สุดของเครื่องเดิมทิ้งทั้งคู่

⚠️ **`clear_furrow > body_width + 2 × runaway_budget` กลายเป็นข้อที่คับที่สุดแทน**
(margin 50 mm) และมันคือข้อที่พึ่ง `crop_foliage_half_width_mm` ซึ่งยังไม่ได้วัด
— ดู [`../../config/README.md`](../../config/README.md#crop_foliage_half_width_mm-คือ-margin-ของ-invariant-ข้อ-5-ทั้งก้อน)

⚠️ **invariant `drive` ตัวล่างมี margin 15.2 mm/s** — `wheel_v_min_mm_s = 51`
เป็นค่าประมาณจาก 15% duty **ยังไม่ได้วัด** ถ้าวัดจริงที่ V3 ได้เกิน **66.2 mm/s**
ต้องลด `omega_max` (เพดานจริง ≈ 29.0 deg/s ที่ `v_left` แตะ 51 พอดี) ห้ามลด
`wheel_v_min`

---

## ค่าที่ตั้งไว้และควรตรวจสอบก่อนสร้างจริง

ตัวเลขในเอกสารนี้เป็น **ค่าเริ่มต้นที่สอดคล้องกัน** ไม่ใช่ค่าที่วัดจากของจริง

| ต้องยืนยัน | ที่ไหน | ถ้าผิดแล้วเกิดอะไร |
|---|---|---|
| `motor_rpm` ~25 (หน้าต่าง 19.4–33.7 RPM) | ก่อนสั่งมอเตอร์ | นอกหน้าต่างนี้ทำให้ invariant ข้อ 6 (ล้อนอกเกิน `wheel_v_max`) หรือข้อ 7 (ล้อในต่ำกว่า deadband) ไม่ผ่าน |
| `wheel_v_min` ที่วัดได้ (V3) — ต้อง ≤ 66.2 mm/s | V3 | เกินแล้วต้องลด `omega_max_deg_s` ห้ามลด `wheel_v_min` |
| FOV กล้องล่าง >= 45° ที่ 850 mm | ก่อนสั่งกล้อง | เห็นร่องไม่ครบ ใบพืชผลไม่แตะขอบเฟรม → นับเป็นวัชพืช |
| `crop_foliage_half_width_mm` **< 55 mm** | V1 (asset พืช) | ถ้า V1 วัดได้ 55+ ต้องขยับ `row_spacing_mm` เป็น 800+ — กระทบทั้ง invariant ข้อ 5 และ corridor พร้อมกัน |
| `soil_variation_mm` <= 62 mm (ไม่ใช่ข้อที่คับที่สุดอีกต่อไป) | V4 (แปลงจริง) | ล้อ Ø250 ไม่พอ ต้องเปลี่ยนล้อใหญ่ขึ้น — margin กว้างกว่าเดิมมาก (190 mm ที่ 15 mm) จึงไม่ใช่จุดเสี่ยงหลักแล้ว |

ความเร็วมอเตอร์ควรอยู่ที่ **2–3 เท่า** ของความเร็วใช้งาน ไม่ใช่มากที่สุดที่หาได้ —
นี่เป็นเรื่องที่ต่างจากงาน stepper ที่เร็วกว่าไม่เสียหาย (`327 / 160` ≈ 2 เท่า ✓)

---

## Sync Enforcement

```bash
pytest tests/unit/test_cad_config_sync.py
```

Test อ่าน `parameters.csv` แล้วเทียบกับ `config/rover.yaml` ตามตารางด้านบน
fail เมื่อค่าไม่ตรง

ใน YAML ค่า derived ทุกตัวต้องมี comment ชี้กลับมา:

```yaml
rover:
  track_width_mm: 430          # derived: cad track_width
```

ไม่มี generator อัตโนมัติโดยตั้งใจ — tooling ที่ผูกกับ Fusion API มีต้นทุนดูแลสูง
เกินความจำเป็นของ POC ตาราง + test จับ drift ได้เพียงพอในขนาดงานนี้

### สิ่งที่ test จับไม่ได้

`test_cad_config_sync.py` ตรวจว่า**ตัวเลขตรงกัน** แต่ตรวจไม่ได้ว่า:

```text
✗ gain ยังเหมาะกับ camera_front_tilt_deg ใหม่หรือไม่
✗ drive_mixing_vectors.csv ถูก regenerate หลังแก้ track_width หรือยัง
✗ FOV กล้องจริงครอบ corridor ได้หรือไม่
```

สามข้อนี้ต้องอาศัยคนจำ — จึงถูกเขียนไว้ที่นี่และใน
[../README.md](../README.md#️-พารามิเตอร์ที่แก้แล้วกระทบมากกว่าที่คิด)

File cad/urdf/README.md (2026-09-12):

# cad/urdf

Robot description ที่เชื่อม CAD เข้ากับ simulation

```text
cad/urdf/
├── weeding_rover.urdf      links, joints, limits, mesh refs
└── meshes/                 mesh ที่ URDF อ้างถึง (copy/symlink จาก ../exports/meshes)
```

---

## Kinematic Chain

ต้องตรงกับ [../../docs/architecture.md](../../docs/architecture.md) และ
[../../hardware/mechanical/coordinate-frames.md](../../hardware/mechanical/coordinate-frames.md)

```text
base_link                     ตัวถัง rover
  │
  ├── wheel_fl_link           continuous   ล้อหน้าซ้าย
  ├── wheel_fr_link           continuous   ล้อหน้าขวา
  ├── wheel_rl_link           continuous   ล้อหลังซ้าย
  ├── wheel_rr_link           continuous   ล้อหลังขวา
  │
  ├── camera_front_link       fixed        tilt 50°, สูง 850 mm, เลื่อนหน้า 0 mm (กึ่งกลาง mast)
  └── camera_down_link        fixed        tilt 0°,  สูง 850 mm
```

**โครงสร้างแบบดาว ไม่ใช่โซ่** — ต่างจาก gantry ที่เป็น
`base → x_carriage → y_carriage → tool` ซ้อนกันเป็นชั้น

ล้อทั้ง 4 เป็นลูกของ `base_link` โดยตรง และไม่มีล้อไหนเป็นพ่อของอะไร
skid-steer ไม่มีข้อต่อบังคับเลี้ยว — ทิศทางเกิดจากความต่างความเร็ว ไม่ใช่จากมุมข้อต่อ

กล้องทั้งสองตัวต่อกับ `base_link` แบบ **fixed** — ขยับตาม rover ทั้งคู่
(ต่างจาก gantry ที่กล้องอยู่กับที่ไม่ขยับตาม carriage)

---

## Joint Origins

| Joint | Origin (x, y, z) เมตร | ที่มา |
|---|---|---|
| `wheel_fl` | `(+0.200, +0.215, 0.125)` | `+wheelbase/2`, `+track_width/2`, `chassis_clearance` |
| `wheel_fr` | `(+0.200, −0.215, 0.125)` | `+wheelbase/2`, `−track_width/2`, `chassis_clearance` |
| `wheel_rl` | `(−0.200, +0.215, 0.125)` | `−wheelbase/2`, `+track_width/2`, `chassis_clearance` |
| `wheel_rr` | `(−0.200, −0.215, 0.125)` | `−wheelbase/2`, `−track_width/2`, `chassis_clearance` |
| `camera_front` | `(0, 0, 0.850)` | `camera_front_offset_x` (= 0, กึ่งกลาง mast), `camera_front_height` |
| `camera_down` | `(0, 0, 0.850)` | `camera_down_height` — mast เดียวกับ camera_front |

`base_link` origin อยู่กึ่งกลางตัวรถที่ระดับ soil reference plane (rover frame,
`hardware/mechanical/coordinate-frames.md`) ดังนั้น `z` ของเพลาล้อ = `chassis_clearance_mm`
พอดี (125 mm = รัศมีล้อ) — ท้องรถอยู่ที่ระดับเพลา ไม่ใช่สูตรอ้อมผ่าน `body_height`
เหมือนเอกสารรุ่นก่อน scale-up

```text
wheelbase 400 mm    → ±0.200 m
track_width 430 mm  → ±0.215 m

ล้อทั้งสี่อยู่ที่ `(±0.200, ±0.215)` — footprint 430 × 400 mm ใกล้จัตุรัสแต่ไม่เป๊ะ
สัดส่วน track:wheelbase = 430:400 ยังเหมาะกับ skid-steer อยู่ (design spec §3.1)
```

---

## Joint Limits

| Joint | Type | Limit | ที่มา |
|---|---|---|---|
| `wheel_*` | `continuous` | **ไม่มี** position limit | ล้อหมุนได้ไม่จำกัด |
| `wheel_*` | velocity limit | 2.616 rad/s | `wheel_v_max_mm_s / (wheel_diameter_mm/2)` |
| `wheel_*` | effort limit | 10.0 N·m | เพดานแรงบิด **peak/stall** ของเกียร์ (`hardware/bom/poc-v3.md`) — **ไม่ใช่ต่อเนื่อง** เพดานต่อเนื่องคือ 5.0 N·m/ล้อ ซึ่งเป็นค่าที่ `test_total_mass_is_under_the_gearbox_ceiling` (มวล 40 kg) อ้างอิง ไม่ใช่ 10.0 นี้ |
| `camera_*` | `fixed` | — | — |

### `continuous` ไม่ใช่ `revolute`

```xml
<joint name="wheel_fl" type="continuous">
```

ถ้าใช้ `revolute` ต้องมี `lower`/`upper` แล้ว Isaac จะหยุดล้อที่ขอบ limit —
อาการคือ rover วิ่งไปได้ระยะหนึ่งแล้วหยุดโดยไม่มี error ซึ่งจะถูกเข้าใจผิดว่าเป็น
ปัญหา friction หรือ command timeout

### Velocity limit ตรวจสอบได้

```text
wheel_rad_s_max = wheel_v_max_mm_s / (wheel_diameter_mm / 2)
                = 327 / 125
                = 2.616 rad/s   →  urdf: 2.616
```

ค่านี้ต้องสอดคล้องกับ `config/rover.yaml` `wheel_v_max_mm_s` — ถ้า URDF จำกัดต่ำกว่า
mixing จะสั่งค่าที่ Isaac ปฏิเสธเงียบ ๆ แล้ว `omega` ที่ได้จะไม่ตรงกับที่สั่ง
(อาการเดียวกับ deadband ของมอเตอร์จริง แต่เกิดใน sim)

---

## Unit Convention

⚠️ URDF ใช้ **เมตรและเรเดียน** ส่วน `config/*.yaml` ใช้ **มิลลิเมตรและองศา**

การแปลงหน่วยผิดตรงนี้เป็น bug ที่หายาก เพราะระบบยังวิ่งได้ แค่ระยะผิดพันเท่า

```text
track_width_mm: 430        →  urdf y = ±0.215
wheel_diameter_mm: 250     →  urdf radius = 0.125
omega_max_deg_s: 25        →  0.436 rad/s
camera_front_tilt_deg: 50  →  0.873 rad (ก่อนรวมกับ optical-frame offset ใน rpy จริงของ joint)
```

จุดแปลงหน่วยมีแค่ 2 ที่ และต้องมี unit test ทั้งคู่ —
ดู [../../hardware/mechanical/coordinate-frames.md](../../hardware/mechanical/coordinate-frames.md#unit-convention)

---

## Collision

| Link | Collision geometry |
|---|---|
| `base_link` | **สามชิ้น ไม่ใช่กล่องเดียว**: กล่องโครงช่วงล้อ `0.500 × 0.340 × 0.125` ที่ `z 0.1875` (z 0.125–0.250, ระดับล้อ) · กล่อง body shell `0.500 × 0.380 × 0.155` ที่ `z 0.3275` (z 0.250–0.405, เหนือหลังคาล้อ) · กระบอก mast รัศมี `0.0175 × 0.500` ที่ `z 0.655` (z 0.405–0.905) |
| `wheel_*` | **cylinder** (รัศมี 0.125 × ยาว 0.090) ไม่ใช่ mesh |
| `camera_*` | ไม่มี collision |

**ยังเป็น primitive ล้วน ไม่มี mesh** — แต่ตอนนี้ `base_link` ต้องเป็น**สามชิ้น**
เพราะรูปทรงจริงไม่ใช่กล่องเดียว: โครงช่วงล้อ (340 mm) แคบกว่า body shell (380 mm)
ที่ยื่นคร่อมได้เพราะอยู่เหนือหลังคาล้อ (ดู
[../../hardware/mechanical/dimensions.md](../../hardware/mechanical/dimensions.md))
ส่วน mast เป็นท่อบางแยกต่างหากที่รับกล้องทั้งสองตัว กล่องเดียวแบบเดิมจะครอบคลุม
ทั้งสามช่วงความกว้างไม่ได้โดยไม่ชนล้อหรือเกินตัวถังจริง

**ล้อต้องเป็น cylinder primitive** — mesh ล้อที่มีดอกยางจะสร้าง contact point
จำนวนมากบน heightfield ทำให้ solver ช้าลงมากและไม่เสถียร โดยไม่ได้ความแม่นยำ
ที่มีความหมาย (grip จริงมาจาก friction coefficient ไม่ใช่รูปดอกยาง)

นี่เป็นจุดที่ต่างจาก design gantry ซึ่งยกเว้นให้หัว tool ใช้ mesh ได้
เพราะรูปทรงหัว tool มีผลกับการสัมผัสดินจริง — ล้อไม่ใช่กรณีนั้น

---

## Import เข้า Isaac

```bash
./scripts/import_urdf.sh
```

สร้าง `sim/isaac/robots/rover/rover_base.usd` (generated, gitignored)
แล้ว `rover.usd` เป็น layer ทับ

**อย่าแก้ `rover_base.usd` โดยตรง** — มันจะถูกเขียนทับทุกครั้งที่ import
ดู [../README.md](../README.md#ทำไมต้องแยก-2-usd-layer)

---

## สิ่งที่ URDF เก็บไม่ได้

ต้องไปอยู่ใน `rover.usd` override layer:

```text
drive gain / stiffness / damping ของ wheel joint
friction ของล้อกับ heightfield        ◄── ค่าที่ tune ยากที่สุดของโปรเจกต์
contact offset / rest offset
articulation solver settings + substep
sensor attachment (2 กล้อง)
camera intrinsic / FOV
```

`friction` เป็นตัวที่สำคัญที่สุด: ต้องพอให้ขับไปข้างหน้าได้ แต่ต้องให้ slip ได้
ตอนเลี้ยว skid-steer ถ้าตั้งสูงเกินจะเลี้ยวไม่ออกหรือ solver ระเบิด

เหตุผลที่ต้องแยก layer ไม่ใช่ความสวยงามของ pipeline — มันคือการไม่ทำ tuning
ชุดนี้หายตอน regenerate จาก CAD

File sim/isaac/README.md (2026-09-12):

# sim/isaac

NVIDIA Isaac Sim module — จำลอง **แปลงปลูกร่องยาว** ที่มี rover 4 ล้อวิ่งในร่องระหว่างแถว

รายละเอียดเต็ม: [../../docs/simulation.md](../../docs/simulation.md)

---

## Layout

```text
sim/isaac/
├── app.py                      # Isaac Sim application entry point
├── world.py                    # World / stage setup
│
├── scenes/
│   ├── weeding_bed.usd         # scene หลัก (ร่องยาว 2000 × 1000 mm)
│   ├── bed_frame.usd           # ขอบแปลง — ยกสูงกว่า wheel_diameter/2
│   ├── soil_heightfield.usd    # ผิวดิน (generate จาก seed)
│   ├── crops/                  # โมเดลพืชผล
│   └── weeds/                  # โมเดลวัชพืช
│
├── robots/
│   └── rover/
│       ├── rover_base.usd      # GENERATED จาก cad/urdf — gitignored, อย่าแก้
│       ├── rover.usd           # override layer: drive gain, friction, damping, sensor
│       ├── wheels.py           # Joint handles: fl, fr, rl, rr
│       └── config.yaml         # Joint drive gains, friction
│
├── sensors/
│   ├── camera_front.py         # → CameraSet.front()   tilt ~50°
│   ├── camera_down.py          # → CameraSet.down()    top-down
│   ├── estop.py                # virtual digital input
│   └── sensor_manager.py
│
├── environments/
│   ├── soil_heightfield.py     # generate ผิวดินจาก seed
│   ├── crop_rows.py            # วางพืชผลเป็นแถว + jitter + row angle + curvature + gap
│   ├── random_weeds.py         # สุ่มวัชพืชในร่อง / ในแถว
│   └── domain_randomization.py
│
└── adapters/
    ├── wheel_adapter.py        # (v, omega) → mixing → wheel joint velocity
    └── io_adapter.py           # virtual digital I/O (estop) + command timeout
```

---

## Boundary

✅ รับผิดชอบ: physics, แปลงดิน/soil heightfield, scene, sensor, rover model,
collision, joint, environment, simulation I/O

❌ **ไม่** รับผิดชอบ: weed detection workflow, row following policy, business logic,
state machine, safety policy หลัก

`adapters/` เป็นจุดเดียวที่ `controller/rover/isaac_rover.py` คุยด้วย

---

## Bed Geometry

```text
Bed                       2000 × 1000 mm
Crop rows                 3 แถว ตามยาว
row_spacing               750 mm      กึ่งกลางแถวถึงกึ่งกลางแถว
crop_foliage_half_width    30 mm
clear furrow              690 mm      ◄── ค่าที่ rover ใช้จริง
Furrows                   2 ร่อง — MVP วิ่งร่องเดียว
```

⚠️ ความกว้างแปลง 1000 mm ด้านบนไม่มีที่มาที่ตรวจสอบได้ในนี้ (ไม่มี config key
หรือ test อ้างอิงมัน) — ดูรายละเอียดที่
[docs/simulation.md#bed-geometry](../../docs/simulation.md#bed-geometry)

**`row_spacing` ไม่ใช่ความกว้างที่ rover วิ่งได้** — `clear_furrow` คือค่าที่
startup invariant ใช้ ไม่ใช่ `row_spacing`

**`bed_frame.usd` ขอบยกสูงกว่าล้อ ไม่ใช่ของประดับ** — MVP ไม่มี bumper switch
ขอบยกเป็น compensating control ทางกายภาพ ต้องมีทั้งใน sim และของจริง

---

## Soil

ดินเป็น **rigid heightfield mesh ผิวไม่เรียบ ±15 mm — ไม่ยุบตัว**

ได้ collision ของล้อกับผิวไม่เรียบ และ CV background ที่สมจริง โดย physics
ยัง stable และรัน headless CI ได้

ไม่ได้: ดินยุบ, ล้อจม, แรงต้าน, ร่องล้อที่ทิ้งไว้

`soil.variation_mm` ใน `config/simulation.yaml` ต้องตรงกับ `bed.soil_variation_mm`
ใน `config/rover.yaml` — เป็น **startup invariant ข้อที่ 9** ไม่ใช่แค่คำแนะนำ

---

## Rover Model

Skid-steer 4WD — 4 ล้อขับ ไม่มีพวงมาลัย

```text
base_link
 ├── wheel_fl · wheel_fr · wheel_rl · wheel_rr    continuous joint, velocity drive
 ├── camera_front   fixed, tilt ~50°
 └── camera_down    fixed, top-down
```

ล้อหน้าและหลังข้างเดียวกันได้คำสั่ง**เหมือนกันเสมอ** (`wheel_adapter.py` ส่งค่าเดียว
ไป 2 joint) ตรงกับของจริงที่ต่อมอเตอร์ขนานเป็นข้าง

**ไม่มี suspension** — chassis แข็ง 4 ล้อ บนผิว ±15 mm จะมีจังหวะล้อลอยและ
เสียแรงขับ นี่ไม่ใช่ข้อบกพร่องของ sim ที่ต้องแก้ ถ้าเกิดใน sim มันจะเกิดของจริงด้วย
**ให้ sim บอกก่อนซื้อล้อ**

---

## `wheel_adapter.py` — mixing ต้องตรงกับ firmware

```text
omega_rad   = omega_deg × pi / 180
v_left      = v - omega_rad × track_width_mm / 2
v_right     = v + omega_rad × track_width_mm / 2
wheel_rad_s = v_side / (wheel_diameter_mm / 2)
```

Saturation ต้อง **scale ทั้งสองข้างตามอัตราส่วนเดิม** ไม่ใช่ clip ข้างเดียว

สูตรนี้ถูก implement ซ้ำใน C++ ที่ firmware — ทั้งคู่ต้องผ่าน
[`config/drive_mixing_vectors.csv`](../../config/drive_mixing_vectors.csv) ตารางเดียวกัน
ผ่าน `tests/unit/test_drive_mixing.py` และ `pio test -e native`

### `io_adapter.py` ต้องจำลอง command timeout ด้วย

`IsaacRover` ต้องดับล้อเมื่อไม่ได้ `drive` ใหม่เกิน `command_timeout_ms`
เหมือน firmware จริง ไม่งั้น scenario `link_lost.yaml` จะผ่านใน sim แต่พฤติกรรม
ไม่ตรงกับของจริง — และ bug ประเภทนี้จะโผล่ที่ V3 ซึ่ง debug แพงกว่ามาก

---

## Sensor Mapping

| Hardware | Simulation |
|---|---|
| Camera front (tilt 50°) | RGB Camera ผูกกับ `base_link` — 640×480 |
| Camera down (top-down) | RGB Camera ผูกกับ `base_link` — 1280×720 |
| DC gear motor × 4 | Continuous joint × 4 (velocity drive) |
| E-stop sense line | Virtual digital input |
| Command timeout (firmware) | `io_adapter.py` ด้วย timestamp ของคำสั่งล่าสุด |

**ไม่มี** endstop · soil contact · servo — ออกจาก MVP ทั้งหมด (กลับมาที่ M3)

`camera_front` ความละเอียดต่ำกว่า `camera_down` โดยเจตนา — front อยู่ใน control loop
ต้องได้ 10 Hz บน Pi และ valley histogram ไม่ต้องการ resolution สูง

---

## Environment Generator

```python
generate_bed(
    bed_length_mm=2000,
    crop_rows=3,
    row_spacing_mm=750,
    crop_spacing_mm=80,
    weed_count=20,
    soil_variation_mm=15,
    row_curvature_mm=40,          # ใหม่
    crop_gap_probability=0.08,    # ใหม่
)
```

### สอง parameter ใหม่สำคัญกว่าที่เหลือทั้งหมด

| Parameter | ถ้าเป็น 0 แล้วเกิดอะไร |
|---|---|
| `row_curvature_mm` | ร่องตรงเป๊ะ → `RowFollower` ผ่านได้ด้วย `gain = 0` เราจะไม่รู้เลยว่ามัน track ได้จริงไหมจนลงแปลง |
| `crop_gap_probability` | ไม่มีต้นหาย → heuristic แยก `row_end`/`row_lost` จะไม่ถูกทดสอบที่จุดที่มันพังจริง |

**ต้องไม่เป็น 0 ในการทดสอบปกติ**

---

## ความเสี่ยง Physics ที่ gantry ไม่มี

Prismatic joint ไม่มี contact dynamics แต่ล้อมีทั้งหมด — **นี่คืองานที่ใช้เวลา
มากที่สุดของ V1 มากกว่า row follower**

1. **Friction** — ต้องพอให้ขับไปข้างหน้าได้ แต่ต้องให้ slip ได้ตอนเลี้ยว skid-steer
   ถ้าตั้งสูงเกินจะเลี้ยวไม่ออกหรือ solver ระเบิด
2. **ล้อลอยบน heightfield** — แรงขับหายเป็นช่วง
3. **Timestep** — contact ที่ความเร็วต่ำบนผิวขรุขระอาจต้อง substep ถี่กว่าเดิม
   กระทบเวลารัน CI

ค่าที่ tune ได้ทั้งหมดอยู่ใน `robots/rover/rover.usd` (override layer) ไม่ใช่ใน URDF

### `omega` ใน sim ก็เป็น nominal เหมือนของจริง

slip ทำให้ `omega` ที่ได้ ≠ `omega` ที่สั่ง — ระบบทนได้เพราะ row follower
ปิดลูปด้วยภาพ แต่ **slip ใน sim ไม่เท่ากับของจริง** จึงโอน gain ข้ามไปไม่ได้
`config/control.yaml` เก็บ gain แยกตาม backend

---

## Run

```bash
./scripts/run_sim.sh
```

---

## Rover Model มาจาก CAD

`rover_base.usd` **generate จาก `cad/urdf/weeding_rover.urdf`** ไม่ได้วาดที่นี่

```bash
./scripts/import_urdf.sh      # เขียนทับ rover_base.usd เสมอ
```

Physics tuning ที่ URDF เก็บไม่ได้ (drive gain, damping, contact offset, friction,
sensor attachment, camera intrinsic) อยู่ใน `rover.usd` ซึ่งเป็น **layer ทับ**
จึงไม่หายตอน regenerate

⚠️ อย่าแก้ `rover_base.usd` โดยตรง — มันถูก gitignored และถูกเขียนทับทุกครั้ง

⚠️ ถ้า `camera_front_tilt_deg` เปลี่ยน **gain ของ row follower ใช้ไม่ได้แล้ว** —
มุมก้มกำหนด lookahead distance ต้อง tune ใหม่ ไม่ใช่แค่ regenerate

ดู [../../cad/README.md](../../cad/README.md#pipeline)

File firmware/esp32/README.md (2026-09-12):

# firmware/esp32

ESP32 low-level controller — **motion + safety ที่ต้องทำงานได้เองโดยไม่พึ่ง Pi**

รายละเอียดเต็ม: [../../docs/hardware.md](../../docs/hardware.md)

---

## Layout

```text
firmware/esp32/
├── platformio.ini
│
├── src/
│   ├── main.cpp                # setup / loop, latest-wins dispatch
│   ├── mixing.cpp              # (v, omega) → v_left, v_right + saturation
│   ├── motors.cpp              # PWM + direction + enable
│   ├── safety.cpp              # command timeout + estop latch
│   └── communication.cpp       # UART2 + JSON line framing
│
├── include/
│   ├── mixing.h
│   ├── motors.h
│   ├── safety.h
│   └── protocol.h              # ต้องตรงกับ protocol/schema.json
│
└── test/
    └── test_mixing.cpp         # native env — อ่าน config/drive_mixing_vectors.csv
```

---

## Scope

```text
ESP32
│
├── Skid-steer mixing        (v, omega) → v_left, v_right → PWM
├── Motor PWM                4 มอเตอร์ ต่อขนานเป็น 2 ช่อง
├── Command timeout          ◄── safety ชั้นที่ต้องเป็นอิสระจาก Pi
├── Motor enable             latch จาก estop / timeout
├── E-stop sense             อ่านไฟจริง ไม่ใช่ตัวแปร software
├── Communication            UART2, latest-wins
└── Watchdog
```

❌ **ไม่** ทำ: weed detection, AI, row following (มันไม่เห็นภาพ),
high-level workflow, การตัดสินใจว่า `row_end` หรือ `row_lost`

**ตัดออกจาก firmware ของ design gantry ทั้งหมด**: stepper STEP/DIR · TMC2209 UART ·
endstop × 4 · servo PWM · soil contact

---

## Command Flow

```text
Pi ──drive seq=N (10 Hz)──► ESP32
                              ├── parse ทุก line ใน buffer
                              ├── ใช้ seq สูงสุด  ทิ้งที่เหลือ
                              ├── mixing → saturation → PWM
                              └── reset timeout timer

Pi ◄──rover_state (20 Hz)──── commanded / last_seq / estop / motors_enabled
```

---

## Latest-wins — ต้องบังคับที่นี่ ไม่ใช่ที่ Pi

serial buffer สะสมได้ ถ้าประมวลผลเรียงตามคิว มันจะเลี้ยวตามคำสั่งเก่า
ที่ Pi ยกเลิกความคิดไปแล้ว

```text
ทุกรอบ loop:  อ่าน line ทั้งหมดที่มีใน buffer
              ใช้ drive ตัวที่ seq สูงสุด  ทิ้งที่เหลือ
              seq <= last_seq  →  ทิ้ง (out of order)
```

`stop` / `emergency_stop` ที่พบใน buffer ต้อง **ทำทันทีไม่ว่าลำดับไหน**
และ override `drive` ทุกตัวในรอบนั้น

`drive` ไม่มี `ack` — ยืนยัน liveness ด้วย `last_seq` ใน telemetry แทน
ถ้าตอบ ack ทุกตัวจะมี traffic 10 Hz ที่ไม่มีใครใช้ และเฟรมที่ตกจะกลายเป็น ERROR

---

## Command Timeout — safety ที่ต้องไม่พึ่ง Pi

```c
if (millis() - last_drive_ms > COMMAND_TIMEOUT_MS) {
    motors_disable();
    fault = COMMAND_TIMEOUT;     // latch — ต้อง reset
}
```

`COMMAND_TIMEOUT_MS` มาจาก `config/safety.yaml` (300 ms) — **ห้าม hard-code**

```text
v_max × command_timeout / 1000 <= runaway_budget    100 × 0.3 = 30 mm <= 60 mm
```

Timeout เป็น **latch**: เมื่อ link กลับมา ต้องรายงาน `command_timeout` แล้วรอ `reset`
**ไม่ใช่ออกตัวต่อเองเมื่อ `drive` ตัวถัดไปมาถึง**

### ทำไมต้องอยู่ฝั่ง firmware

```text
Pi แครช / สาย UART หลุด  →  ESP32 ยังมีไฟ  →  ดับมอเตอร์เอง  ✓
```

ถ้า timeout อยู่ฝั่ง Pi แล้ว Pi แครช จะไม่มีใครสั่งหยุด

⚠️ **ESP32 ต้องมี buck ของตัวเอง ไม่กินไฟจาก USB ของ Pi** — ไม่งั้น safety ชั้นนี้
พึ่ง Pi ทางไฟฟ้าอยู่ดี ดู [../../hardware/electrical/power.md](../../hardware/electrical/power.md#️-esp32-ต้องไม่กินไฟจาก-pi)

---

## Skid-Steer Mixing

```c
omega_rad = omega_deg * PI / 180.0f;
v_left    = v - omega_rad * TRACK_WIDTH_MM / 2.0f;
v_right   = v + omega_rad * TRACK_WIDTH_MM / 2.0f;
```

ล้อหน้าและหลังข้างเดียวกันได้ค่าเดียวกัน (ต่อขนานทางไฟอยู่แล้ว)

### Saturation ต้อง scale ไม่ clip

```c
float peak = fmaxf(fabsf(v_left), fabsf(v_right));
if (peak > WHEEL_V_MAX_MM_S) {
    float k = WHEEL_V_MAX_MM_S / peak;
    v_left  *= k;
    v_right *= k;                 // อัตราส่วนเดิม → omega ไม่เปลี่ยน
}
```

การ clip ข้างเดียวจะเปลี่ยน `omega` ที่ได้จริงโดยเงียบ

### ⚠️ Deadband — ต้องรู้ ไม่ใช่ต้องแก้

มอเตอร์เกียร์ DC ไม่ออกตัวใต้ ~15% duty (≈ 51 mm/s ที่ล้อ Ø65)

```text
ที่ omega = 60 deg/s:  v_left = 37 mm/s  (11%)  ✗ ล้อหยุด แต่ firmware คิดว่าสั่งแล้ว
ที่ omega = 40 deg/s:  v_left = 58 mm/s  (17%)  ✓
```

firmware **ไม่ต้องชดเชย deadband** — มันถูกกันด้วย startup invariant ที่ฝั่ง Pi
(`omega_max` ถูกจำกัดไว้ที่ 40 ซึ่งเพดานจริงคือ 46)

สิ่งที่ firmware ต้องทำคือ **ปฏิเสธคำสั่งที่เป็นไปไม่ได้** แทนที่จะพยายามทำ:

```text
v == 0 && omega != 0   →  ตอบ error  (turn-in-place อยู่นอก MVP
                          ล้อทั้งสองข้างจะอยู่ใน deadband และต้องกลับทิศ)
```

### Golden vectors — สูตรนี้ถูก implement ซ้ำใน Python

```text
config/drive_mixing_vectors.csv     ◄── source of truth เดียว
        ├──> tests/unit/test_drive_mixing.py       Python / IsaacRover
        └──> firmware/esp32/test/test_mixing.cpp   ที่นี่
```

```bash
pio test -e native          # ไม่ต้องมีบอร์ด
```

ถ้าตัวใดตัวหนึ่ง fail แปลว่า implementation สองภาษาเพี้ยนจากกัน —
**แก้ implementation ห้ามแก้ตาราง**

ถ้า `track_width_mm` หรือ `wheel_v_max_mm_s` ใน CAD/config เปลี่ยน
ต้อง **regenerate ตารางทั้งชุด** ไม่ใช่แก้ทีละแถว

---

## E-stop

```text
แบต ──┬── E-stop (latching NC) ── driver ── มอเตอร์
      │         └──► sense ──► GPIO 39 (ต้องมี pull-up ภายนอก)
      └── buck 5V ── Pi + ESP32     ◄── ไม่ผ่าน E-stop
```

E-stop ตัดไฟมอเตอร์ **ทางกายภาพ** — sense line มีไว้ให้ firmware รายงานสถานะ
ไม่ใช่ให้ firmware เป็นคนหยุด

firmware ต้อง:

```text
[ ] อ่าน sense line ทุกรอบ loop ใส่ใน rover_state.estop
[ ] ดึง EN LOW ทันทีที่ sense active (กันมอเตอร์ออกตัวตอนปล่อยปุ่ม)
[ ] ปฏิเสธ reset ขณะ sense ยัง active → ตอบ error code emergency_stop
```

⚠️ `GPIO 39` เป็น input only และ **ไม่มี internal pull-up** —
`pinMode(39, INPUT_PULLUP)` compile ผ่านแต่ไม่ทำอะไรเลย ต้องใส่ 10 kΩ ภายนอก
ดู [../../hardware/electrical/wiring.md](../../hardware/electrical/wiring.md#️-gpio-34-35-36-39-ไม่มี-internal-pull-up)

---

## Boot Safety

```text
[ ] EN ต้องเป็น LOW ตั้งแต่ก่อน setup() เสร็จ
[ ] motors_enabled = false จนกว่าจะได้ drive ตัวแรก
[ ] fault = COMMAND_TIMEOUT เป็นสถานะเริ่มต้น (ไม่ใช่ OK)
```

ถ้า EN ลอยตอนบูต มอเตอร์อาจหมุนก่อน firmware พร้อม — บน rover นี่คือการออกตัวเอง

`uptime_ms` ใน telemetry มีไว้ให้ Pi ตรวจจับการรีบูตกลางทาง (ค่าลดลง)
ไม่ใช่ใช้คำนวณ latency

---

## Build & Test

```bash
./scripts/flash_esp32.sh       # build + upload
pio test -e native            # unit test บน host ไม่ต้องมีบอร์ด
```

`platformio.ini` ต้องมี 2 environment:

```text
[env:esp32dev]     บอร์ดจริง
[env:native]       host — สำหรับ test_mixing.cpp
```

`mixing.cpp` ต้องไม่ include อะไรที่ผูกกับ Arduino/ESP-IDF เพื่อให้ compile
ใน `native` ได้ — ถ้ามันต้องพึ่ง `analogWrite` มันไม่ใช่ pure function
และจะ test ข้ามภาษาไม่ได้

---

## HIL — ต้องล้อลอย

```text
ยกล้อลอย → ถอดสาย UART · กด E-stop · ส่ง seq ย้อนหลัง · ยัด buffer · วัด deadband
         → ผ่านครบแล้วจึงวางลงพื้น
```

รายการเต็ม: [../../hardware/mechanical/assembly.md](../../hardware/mechanical/assembly.md#bench-test-checklist--ล้อลอย-ขั้นที่-11)

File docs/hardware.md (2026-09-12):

# Hardware & Firmware

---

## Scope

เอกสารนี้ครอบคลุม **firmware และการ integrate** เท่านั้น

ของจริงทางกายภาพ — รายการของ, ขนาด, การประกอบ, สายไฟ — อยู่ที่ [`hardware/`](../hardware/README.md)

| ต้องการ | ไปที่ |
|---|---|
| รายการของ / ข้อกำหนดก่อนซื้อ | [hardware/bom/poc-v3.md](../hardware/bom/poc-v3.md) |
| ขนาด rover | [hardware/mechanical/dimensions.md](../hardware/mechanical/dimensions.md) |
| ลำดับประกอบ + ค่าที่ต้องวัด | [hardware/mechanical/assembly.md](../hardware/mechanical/assembly.md) |
| Pin map + กับดัก ESP32 | [hardware/electrical/wiring.md](../hardware/electrical/wiring.md) |
| ไฟ / power budget | [hardware/electrical/power.md](../hardware/electrical/power.md) |
| นิยาม coordinate frame | [hardware/mechanical/coordinate-frames.md](../hardware/mechanical/coordinate-frames.md) |
| ขนาดต้นทาง (CAD) | [cad/parameters/README.md](../cad/parameters/README.md) |

เส้นแบ่ง: *ถ้าต้องใช้ไขควง = `hardware/` · ถ้าต้องใช้ compiler = ที่นี่*

---

## สองคอมพิวเตอร์ ไม่ใช่หนึ่ง

```text
Raspberry Pi (บน rover)              ESP32
├── Perception (2 กล้อง)              ├── Skid-steer mixing
├── RowFollower                      ├── Motor PWM
├── State machine                    ├── Command timeout  ◄── safety ชั้นที่ต้องเป็นอิสระ
├── Safety: row-loss watchdog        ├── Motor enable
└── Startup invariants               ├── E-stop sense
                                     └── Watchdog
```

**ESP32 ต้องปลอดภัยได้เองโดยไม่พึ่ง Pi** — ถ้า Pi แครชหรือสาย USB หลุด
มอเตอร์ต้องดับเองภายใน `command_timeout_ms` นี่คือเหตุผลที่ command timeout
อยู่ฝั่ง firmware ไม่ใช่ฝั่ง Pi

---

## Firmware Scope

```text
ESP32
│
├── Skid-steer mixing        (v, omega) → v_left, v_right → PWM
├── Motor PWM                4 มอเตอร์ ต่อขนานเป็น 2 ช่อง
├── Command timeout          ไม่ได้ drive เกิน 300 ms → ดับมอเตอร์
├── Motor enable             latch จาก estop / timeout
├── E-stop sense             อ่านไฟจริงหลัง E-stop ไม่ใช่ตัวแปร software
├── Communication            JSON บรรทัดละ message, latest-wins
└── Watchdog
```

**ไม่ควร** ให้ ESP32 ทำ:

- Weed detection · AI
- Row following (มันไม่เห็นภาพ)
- High-level workflow
- การตัดสินใจว่า `row_end` หรือ `row_lost`

**ตัดออกจาก firmware เดิมทั้งหมด**: stepper STEP/DIR · TMC2209 UART · endstop ×4 ·
servo PWM · soil contact

---

## Firmware Layout

```text
firmware/esp32/
│
├── platformio.ini
│
├── src/
│   ├── main.cpp
│   ├── mixing.cpp              # (v, omega) → v_left, v_right + saturation
│   ├── motors.cpp              # PWM + direction + enable
│   ├── safety.cpp              # command timeout + estop latch
│   └── communication.cpp       # JSON line parse, latest-wins
│
├── include/
│   ├── mixing.h
│   ├── motors.h
│   ├── safety.h
│   └── protocol.h
│
└── test/
    └── test_mixing.cpp         # native env — อ่าน config/drive_mixing_vectors.csv
```

---

## Skid-Steer Mixing — และกับดักที่ต้องรู้

```text
omega_rad = omega_deg * PI / 180.0
v_left    = v - omega_rad * track_width_mm / 2
v_right   = v + omega_rad * track_width_mm / 2
duty      = v_side / wheel_v_max_mm_s
```

### ต้อง scale ไม่ clip

ถ้าล้อข้างใดเกิน `wheel_v_max_mm_s` → **ลดทั้งสองข้างตามอัตราส่วนเดิม**
การ clip ข้างเดียวเปลี่ยน `omega` ที่ได้จริงโดยเงียบ

### ⚠️ Deadband — เหตุผลที่ `omega_max` เป็น 25 ไม่ใช่ 40

มอเตอร์เกียร์ DC **ไม่ออกตัวใต้ ~15% duty**

```text
ล้อ Ø250 mm · มอเตอร์ ~25 RPM → wheel_v_max = 327 mm/s
deadband ≈ 15% ของ 327       → ~49 mm/s แต่ค่าที่เก็บไว้คือ 51 mm/s
                                (เข้มกว่าประมาณการ ยังไม่ได้วัดจริงที่ V3)

track_width ขยับจาก 120 เป็น 430 mm ในรอบ scale-up — differential ต่อองศาจึงโต
ขึ้นตาม ทำให้ omega_max เดิม (40 deg/s) ใช้ไม่ได้อีกต่อไป:

ที่ omega = 40 deg/s:  differential = 150.1 mm/s → v_left = 160−150.1 =  9.9 mm/s (3%)  ✗ ล้อหยุดหมุนแต่ firmware คิดว่าสั่งแล้ว
ที่ omega = 25 deg/s:  differential =  93.8 mm/s → v_left = 160− 93.8 = 66.2 mm/s (20%) ✓ เหนือ deadband 15.2 mm/s

เพดานจริงของ omega_max ที่ track 430 คือ ~29.0 deg/s — จาก invariant ข้อ 7
(`controller/startup_checks.py`): v_max − radians(omega) × track/2 >= wheel_v_min
→ 160 − 51 = 109 → radians(omega) <= 109/215 = 0.50698 → omega <= 29.05°
เลือก 25 เพื่อให้มี margin ไม่ใช่เพราะ 25 เป็นค่าสูงสุดที่ทำได้
```

ล้อข้างในที่หยุดหมุนทำให้ rover เลี้ยวแรงกว่าที่สั่ง **โดยไม่มีสัญญาณบอก** —
ไม่มี encoder ไม่มีใครรู้ ต้องกันที่ startup invariant

`wheel_v_min_mm_s` **ต้องวัดจริงที่ V3** ก่อนวางล้อลงพื้น — ค่า 51 เป็นค่าประมาณ

### Turn-in-place อยู่นอก MVP

`v = 0` กับ `omega` ใด ๆ ทำให้ล้อทั้งสองข้างอยู่ใน deadband และต้องกลับทิศ
MVP ไม่ต้องใช้ (วิ่งร่องเดียวแล้วหยุด) — firmware ควร**ปฏิเสธ** `drive` ที่
`v == 0 && omega != 0` แล้วตอบ `error` แทนที่จะพยายามทำ

### สูตรนี้ถูก implement ซ้ำใน Python

`controller/rover/mixing.py` มีสูตรเดียวกัน แชร์โค้ดกันไม่ได้เพราะต่างภาษา
ทั้งสองต้องผ่าน golden vector ตารางเดียวกัน:

```bash
pytest tests/unit/test_drive_mixing.py         # Python
pio test -e native                             # C++
```

ทั้งคู่อ่าน [`config/drive_mixing_vectors.csv`](../config/drive_mixing_vectors.csv)

---

## Command Flow

```text
Controller (Pi)                      ESP32
│                                    │
├── drive seq=N (10 Hz) ────────────►│
│                                    ├── parse ทุก line ใน buffer
│                                    ├── ใช้ seq สูงสุด ทิ้งที่เหลือ
│                                    ├── mixing → saturation → PWM
│                                    └── reset timeout timer
│                                    │
│◄──── rover_state (20 Hz) ──────────┤ commanded / last_seq / estop / motors_enabled
```

### Latest-wins ต้องบังคับที่ฝั่ง ESP32

serial buffer สะสมได้ ถ้าประมวลผลเรียงตามคิว มันจะเลี้ยวตามคำสั่งเก่า
ที่ Pi ยกเลิกความคิดไปแล้ว

```text
ทุกรอบ loop:  อ่าน line ทั้งหมดที่มีใน buffer
              ใช้ drive ตัวที่ seq สูงสุด  ทิ้งที่เหลือ
              seq <= last_seq  →  ทิ้ง (out of order)
```

`stop` / `emergency_stop` ที่พบใน buffer ต้อง **ทำทันทีไม่ว่าลำดับไหน**
และ override `drive` ทุกตัวในรอบนั้น

---

## Command Timeout — safety ชั้นที่ต้องเป็นอิสระ

```c
if (millis() - last_drive_ms > COMMAND_TIMEOUT_MS) {
    motors_disable();
    fault = COMMAND_TIMEOUT;     // latch — ต้อง reset
}
```

ค่ามาจาก `config/safety.yaml` `command_timeout_ms: 300` — firmware ต้องไม่ hard-code

```text
v_max × command_timeout / 1000 <= runaway_budget      160 × 0.3 = 48 mm <= 60 mm
```

Timeout เป็น **latch** — เมื่อ link กลับมา firmware ต้องรายงาน `command_timeout`
แล้วรอ `reset` ไม่ใช่ออกตัวต่อเองเมื่อ `drive` ตัวถัดไปมาถึง

---

## E-stop

```text
แบต 24V LiFePO4 ──┬── E-stop (latching NC) ── driver ── มอเตอร์
                  │         └──► sense line ──► ESP32 GPIO
                  └── buck 5V ── Pi + ESP32        ◄── ไม่ผ่าน E-stop
```

E-stop **ตัด motor rail ทางไฟ** ไม่ใช่บอก firmware ให้หยุด

ไฟ logic ไม่ถูกตัด → Pi และ ESP32 ยังมีไฟ → **ยังรายงานได้ว่า `estop: true`**
ถ้าตัดทั้งระบบ จะได้ rover ที่หยุดจริงแต่เงียบ แยกไม่ออกจากแบตหมดหรือแครช

firmware ต้อง**ปฏิเสธ** `reset` ขณะที่ sense line ยัง active —
ตอบ `error` code `emergency_stop` แทน `ack`

รายละเอียดการเดินสาย: [../hardware/electrical/wiring.md](../hardware/electrical/wiring.md)

---
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

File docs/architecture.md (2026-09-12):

# Architecture

## 1. Objective

Repository นี้ออกแบบให้พัฒนา Mini Smart Weeding Robot โดยเริ่มจาก Simulation
แล้วเปลี่ยนไปใช้ Hardware จริงภายหลังได้ โดยไม่ต้องรื้อ architecture หลัก

Form factor: **rover skid-steer 4 ล้อ วิ่งในร่องระหว่างแถวปลูก**

(Rover Base V0 — 650 × 520 mm, ~35 kg: ร่องกว้างขึ้นตามตัวรถ `row_spacing_mm`
จึงเป็น **750 mm** ไม่ใช่ 350 mm ของรอบพัฒนาก่อนหน้า — ดู
[docs/superpowers/specs/2026-09-12-rover-base-v0-scale-up-design.md](superpowers/specs/2026-09-12-rover-base-v0-scale-up-design.md)
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

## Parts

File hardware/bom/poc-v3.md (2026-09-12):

# BOM — POC v3 (Rover Base V0, 650 × 520 mm)

**Status:** Requirement envelope — **ยังไม่เลือก part number**
**Supersedes:** BOM รุ่น v2 ทั้งฉบับ (เครื่องคนละขนาด ไม่ใช่รุ่นปรับปรุง) — ไฟล์นั้นถูกลบออกจาก tree แล้ว อยู่ใน git history
**Design:** [`docs/superpowers/specs/2026-09-12-rover-base-v0-scale-up-design.md`](../../docs/superpowers/specs/2026-09-12-rover-base-v0-scale-up-design.md) §8

---

## ทำไมเอกสารนี้ไม่มี part number

Design decision S10: รอบนี้ให้ความสำคัญกับ CAD ที่ปลดล็อกงาน development ก่อน
ตัวเลขทุกตัวด้านล่าง**คำนวณได้จากเรขาคณิตและ invariant** ไม่ได้มาจาก catalogue

ทุกแถวมี gate เดียวกัน: **ยืนยันกับ datasheet ก่อนสั่ง** และเมื่อเลือกของจริงแล้ว
ต้องกลับมาแทนที่ `mass` ใน `tools/generate_sim_meshes.py` ด้วยค่าที่ชั่งได้จริง

---

## Drivetrain

| # | Item | Qty | ข้อกำหนด | Gate |
|---|---|---:|---|---|
| D1 | DC gear motor 24 V **~25 RPM** — brushed planetary, encoder ในตัว | 4 | ดู §หน้าต่างความเร็ว | ⚠️ ยืนยัน datasheet |
| D2 | Motor driver ≥ 10 A/ช่อง ที่ 24 V | 2 (dual) หรือ 4 | ดู §กระแส | ⚠️ ยืนยัน datasheet |
| D3 | ล้อ Ø250 × 90 mm ดอกยางเกษตร + ดุม | 4 | bolt circle 60 mm ตรงกับ D1 | ⚠️ ยืนยัน datasheet |
| D4 | แบตเตอรี่ 24 V LiFePO4 20 Ah (480 Wh) + BMS | 1 | วางต่ำและกึ่งกลาง | ⚠️ ยืนยัน datasheet |
| D5 | E-stop latching relay ตัด rail 24 V ของมอเตอร์ | 1 | ทนกระแส peak 15 A | ⚠️ ยืนยัน datasheet |

## Compute — ไม่เปลี่ยนจาก v2

| # | Item | Qty | หมายเหตุ |
|---|---|---:|---|
| C1 | Raspberry Pi 5 | 1 | Design decision S9 — override source spec §10 ที่ระบุ Jetson |
| C2 | ESP32 DevKit | 1 | ไม่เปลี่ยน `firmware/` ทั้งชุดใช้ต่อได้ |
| C3 | กล้อง USB ×2 | 2 | front ≥ 60° HFOV · down ≥ 45° HFOV |

Jetson เป็นเส้นทางของ M3 ตอนมี CNN weed detector — perception ตอนนี้เป็น ExG + Otsu
ต่อเฟรม ซึ่ง Pi 5 รันสบาย และ `bridge/` + `firmware/` ต่อไว้แล้วทั้งชุด

---

## หน้าต่างความเร็วมอเตอร์ — ทำไมต้อง 25 RPM

Invariant สองข้อบีบจากคนละด้าน ที่ `track_width = 430 mm`, `v_max = 160 mm/s`,
`omega_max = 25 deg/s`:

```text
differential = radians(25) x 430/2 = 93.81 mm/s

ข้อ 6  ล้อนอก 160 + 93.81 = 253.81 <= wheel_v_max   ->  rpm >= 19.4
ข้อ 7  ล้อใน  160 - 93.81 =  66.19 >= deadband
       ที่ 15% duty                                  ->  rpm <= 33.7
```

```text
หน้าต่าง                 19.4 – 33.7 RPM
เลือก                    25 RPM
wheel_v_max = (25/60) x pi x 250 = 327 mm/s
cruise 160 / 327         = 49% duty     ✓ พ้น deadband สบาย
```

49% duty เป็นไปตามกฎเดียวกับ v2: **ความเร็วมอเตอร์ควรอยู่ที่ 2–3 เท่าของความเร็วใช้งาน
ไม่ใช่มากที่สุดที่หาได้** — ที่ v2 ข้อนี้ตัดเกียร์ 125:1 ทิ้งเพราะเร็วไป 4%

⚠️ Design spec §7.1 และ §8.3 พิมพ์หน้าต่างนี้ไว้ที่ 18.6–28.6 RPM — เลขนั้นคำนวณที่
`v_max = 150 mm/s` ก่อนที่ design decision S7 จะปรับ `v_max` เป็น 160 mm/s และไม่เคย
คำนวณใหม่ให้ตรงกัน spec เป็นบันทึกการตัดสินใจ ณ ตอนที่ตัดสินใจไว้เฉย ๆ — เอกสารนี้
(BOM) เป็นเอกสารที่ใช้สั่งของจริง หน้าต่างที่ใช้งานคือ 19.4–33.7 RPM ด้านบน

---

## แรงบิด

ที่มวลประมาณ **35 kg** และล้อรัศมี 0.125 m:

```text
rolling อย่างเดียว (Crr 0.15 ดินร่วน)     1.61 N·m/ล้อ
ทางชัน 15° + rolling                     4.33 N·m/ล้อ   <- continuous
skid-steer pivot (mu_lat 0.7)            5.5  N·m/ล้อ   <- peak
```

| | ข้อกำหนด |
|---|---|
| Continuous | **≥ 5 N·m ต่อล้อ** |
| Peak | **≥ 10 N·m ต่อล้อ** |

### เพดานมวลที่แรงบิด continuous รับได้

```text
แรงลากรวม = 4 x 5 N·m / 0.125 m = 160 N
ต้านที่ 15° + rolling = m x 9.81 x (sin15 + 0.15 x cos15) = m x 3.960

m_max = 160 / 3.960 = 40.4 kg   ->  เพดาน 40 kg
```

**นี่คือเพดานที่ `test_total_mass_is_under_the_gearbox_ceiling` บังคับ**
แทนเพดาน 2.3 kg ของ v2 ที่มาจากเกียร์ 250:1 ตัวเล็ก

⚠️ ประมาณการมวลคือ 35 kg **±20%** ขอบบนคือ 42 kg ซึ่ง**เกินเพดาน** — ถ้าของจริง
ชั่งได้เกิน 40 kg ต้องขึ้นมอเตอร์แรงบิดสูงขึ้น ไม่ใช่ผ่อนเพดาน

---

## กระแสและพลังงาน

```text
drive continuous  4 x 5 N·m x 2.618 rad/s / 0.6 eff = ~87 W   ->  ~3.6 A ที่ 24 V
drive peak        ~250 W                                      ->  ~10 A
Pi 5 + กล้อง + ESP32                                          ->  ~30 W

รวมเฉลี่ย ~110 W  ->  480 Wh / 110 W = ~4.4 ชม.
```

Driver ต้องรับ **≥ 10 A/ช่อง continuous** เพราะ stall ของมอเตอร์แต่ละตัวอยู่เหนือ
กระแสใช้งานมาก และ skid-steer เข้าใกล้ stall ทุกครั้งที่หมุนอยู่กับที่บนดิน

---

## มวลโดยประมาณ — 35 kg ±20%

| | kg |
|---|---:|
| ล้อ 4 × (ยาง + วงล้อ + ดุม) | 7.2 |
| มอเตอร์เกียร์ 4 ตัว | 6.0 |
| โครง (อลูมิเนียม 30×30 + แผ่น) | 8.5 |
| Body shell | 3.0 |
| แบตเตอรี่ 24 V LiFePO4 20 Ah | 5.0 |
| Motor driver + power box | 1.5 |
| Pi 5 + ESP32 + สายไฟ | 1.5 |
| Mast + sensor head | 1.2 |
| น็อต + เบ็ดเตล็ด | 1.1 |
| **รวม** | **35.0** |

การกระจายมวลนี้ถูก encode ไว้ใน `tools/generate_sim_meshes.py` (`MASS_ITEMS`)
ซึ่งเป็นที่ที่ URDF ได้ mass และ inertia มา — **แก้ที่นั่นที่เดียว**

---

## ข้อจำกัดเชิงกลที่มาจาก ground clearance

`chassis_clearance = 125 mm` เท่ากับรัศมีล้อพอดี ท้องรถจึงอยู่**ที่ระดับเพลา**

> ห้ามมี hub carrier, bearing block, ตัวมอเตอร์, หัวน็อต หรือสายไฟ
> อยู่ต่ำกว่าแนวศูนย์กลางเพลา

แปลว่า **ขับตรงที่เพลาเท่านั้น** ไม่มีเฟืองทด ไม่มีโซ่ ไม่มีสายพานที่ห้อยลงมา
และหน้าแปลนมอเตอร์ต้องยึดเข้าโครงที่ระดับเพลาพอดี (bolt circle 60 mm)

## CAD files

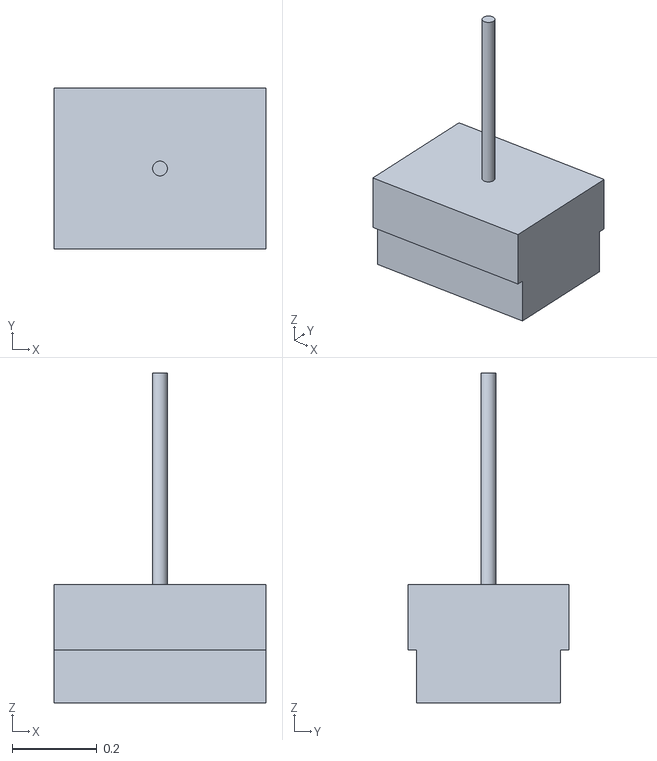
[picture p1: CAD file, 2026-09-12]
cad/exports/meshes/base_link.stl
0.5 x 0.38 x 0.78

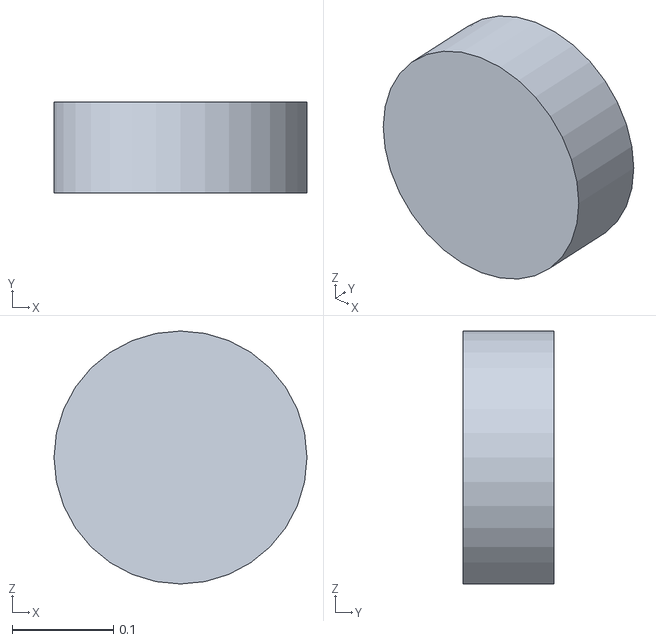
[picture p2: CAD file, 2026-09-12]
cad/urdf/meshes/wheel.obj
0.25 x 0.09 x 0.25

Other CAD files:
cad/exports/step/rover_base_v0.step
cad/exports/stl/sensor_head.stl
cad/exports/meshes/wheel.stl
cad/urdf/meshes/base_link.obj
cad/exports/meshes/base_link.obj
cad/fusion/rover_base_v0.f3d

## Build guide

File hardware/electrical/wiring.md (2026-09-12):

# Wiring

การเดินสายและ pin mapping ของ ESP32

⚠️ Pin ที่นี่ต้องตรงกับ `firmware/esp32/include/motors.h` — ถ้าไม่ตรง อาการคือ
มอเตอร์ไม่หมุนหรือหมุนผิดข้าง ซึ่งใช้เวลา debug นานเกินความจำเป็น

---

## ภาพรวม

```text
             Raspberry Pi                      ESP32
          ┌─────────────────┐           ┌─────────────────┐
camera ──►│ GPIO14 TX ──────┼──────────►│ GPIO16 RX2      │
front     │ GPIO15 RX ◄─────┼───────────┤ GPIO17 TX2      │
camera ──►│ GND ────────────┼───────────┤ GND             │
down      └─────────────────┘           └────┬───┬────┬───┘
                                             │   │    │
                                    PWM ◄────┘   │    └──► GPIO39 estop sense
                                                 └──► GPIO27 EN
                                ┌────────────────────────┐
                                │  H-bridge × 2 ช่อง      │
                                └───┬────────────────┬───┘
                                    ▼                ▼
                              motor_fl+rl      motor_fr+rr
                               (ซ้าย ขนาน)      (ขวา ขนาน)
```

Pi กับ ESP32 คุยกันด้วย **UART ไม่ใช่ USB** — เหตุผลอยู่ที่ [§UART ไม่ใช่ USB](#uart-ไม่ใช่-usb)

---

## ESP32 Pin Map

### Motor driver (BTS7960 / IBT-2 × 2)

⚠️ `BTS7960 / IBT-2` ถูกเลือกไว้สำหรับมอเตอร์ 12 V ของเครื่องเดโมเดิม —
Rover Base V0 ยังไม่ได้เลือก driver 24 V ตัวจริง `hardware/bom/poc-v3.md` D2
ระบุแค่ข้อกำหนดที่ตัวที่มาแทนต้องผ่าน: **≥ 10 A/ช่อง ที่ 24 V** ส่วน pin map
ด้านล่างนี้ (RPWM/LPWM/EN) ยังเป็นรูปแบบของไดรเวอร์ตระกูลนี้ ต้องทวนใหม่เมื่อ
เลือก part จริง

| สัญญาณ | GPIO | หมายเหตุ |
|---|---|---|
| LEFT RPWM | 25 | LEDC channel, ~1 kHz |
| LEFT LPWM | 26 | |
| RIGHT RPWM | 32 | |
| RIGHT LPWM | 33 | |
| EN (ร่วมทั้งสอง driver) | 27 | R_EN + L_EN ผูกเข้าด้วยกัน active HIGH |

RPWM / LPWM คู่กันให้ทั้งทิศทางและความเร็ว: ขาหนึ่ง PWM อีกขา 0

**ห้าม PWM ทั้งสองขาพร้อมกัน** — จะเป็น shoot-through ทำให้ MOSFET ร้อนและพัง

`EN` เป็นขาที่ `safety.cpp` ใช้ดับมอเตอร์เมื่อ command timeout หรือ estop —
ต้องดึง LOW เป็น default ตอนบูต ไม่งั้นมอเตอร์อาจหมุนก่อน firmware พร้อม

### Serial ไป Pi (UART2)

| สัญญาณ | GPIO | ไปที่ |
|---|---|---|
| TX2 | 17 | Pi GPIO15 (RXD) |
| RX2 | 16 | Pi GPIO14 (TXD) |
| GND | GND | Pi GND (**บังคับ**) |

ทั้งสองบอร์ดเป็น **3.3 V logic** — ต่อตรงได้ ไม่ต้องมี level shifter

Baud: **115200** (ใช้ ~30% ของ link) ดู [../../docs/protocol.md](../../docs/protocol.md#transport)

### Safety

| สัญญาณ | GPIO | หมายเหตุ |
|---|---|---|
| E-stop sense | 39 | **input only — ต้องมี external pull-up** |

---

## UART ไม่ใช่ USB

ทางที่ง่ายกว่าคือเสียบ USB จาก Pi ไป ESP32 DevKit — ได้ทั้ง serial และไฟเลี้ยง
แต่**ทำลาย safety layer ที่ MVP พึ่งอยู่**

```text
USB:   ESP32 กินไฟจาก Pi  →  Pi ดับ = ESP32 ดับ = ไม่มีใครดับมอเตอร์
UART:  ESP32 มี buck ของตัวเอง  →  Pi ดับ = ESP32 ยังอยู่ = command timeout ทำงาน
```

command timeout เป็น safety ชั้นที่ต้อง **ไม่พึ่ง Pi** ถ้า ESP32 กินไฟจาก Pi
ชั้นนั้นก็พึ่ง Pi ทางไฟฟ้าอยู่ดี

USB ยอมรับได้สำหรับ flash firmware และ bench debug — **แต่ไม่ใช่สำหรับ link
ที่ใช้งานจริง** ดู [../../docs/architecture.md](../../docs/architecture.md#7-safety--3-ชั้น-3-เจ้าของ)

---

## ⚠️ GPIO 34, 35, 36, 39 ไม่มี internal pull-up

ขาเหล่านี้เป็น **input only** และ **ไม่มี pull-up/pull-down ภายใน**

ถ้าต่อ switch โดยไม่ใส่ตัวต้านทานภายนอก ขาจะลอย และอ่านค่าได้แบบสุ่ม —
อาการคือ E-stop trigger เองตอนมอเตอร์หมุน

**ต้องใส่ pull-up 10 kΩ ไป 3.3 V**

```text
3.3 V
  │
 10 kΩ
  │
  ├──────── GPIO 39
  │
E-stop sense (หลังหน้าสัมผัส NC)
  │
 GND
```

`pinMode(39, INPUT_PULLUP)` **ไม่มีผล** — compile ผ่าน ไม่มี error แต่ไม่ได้ทำอะไรเลย
เป็นกับดักที่พบบ่อยที่สุดของ ESP32

### GPIO ที่ห้ามใช้

```text
6–11        ต่อกับ flash — ใช้แล้วบูตไม่ขึ้น
0, 2, 15    strapping pin — มีแรงดันตอนบูตแล้วเข้า mode ผิด
12          strapping pin (MTDI) — HIGH ตอนบูต → flash voltage 1.8 V → บูตไม่ขึ้น
1, 3        UART0 — ใช้สำหรับ flash และ boot log
34–39       input only — ไม่ output ได้ และไม่มี pull-up
```

pin map ข้างบนหลีกเลี่ยงทั้งหมดแล้ว — 25, 26, 27, 32, 33 เป็น output ปกติ
และ 16, 17 เป็น UART2 ที่ไม่ชนกับ boot

---

## Switch Wiring — NC เสมอ

E-stop ต่อแบบ **normally closed**

```text
ปกติ:      วงจรปิด  → sense อ่านได้ LOW   → ปลอดภัย
ถูกกด:     วงจรเปิด  → sense อ่านได้ HIGH  → หยุด
สายขาด:    วงจรเปิด  → sense อ่านได้ HIGH  → หยุด    ◄── สำคัญ
```

สายขาดต้องให้ผลเหมือนถูกกด ไม่ใช่เหมือนปกติ

ถ้าต่อแบบ NO สายที่หลุดจะทำให้ระบบคิดว่า "ยังไม่มีใครกด" แล้ววิ่งต่อไป —
เป็นความผิดพลาดที่ไม่แสดงอาการจนกว่าจะเกิดความเสียหาย

MVP **ไม่มี endstop และไม่มี bumper** จึงมี switch แค่ตัวนี้ตัวเดียว —
ยิ่งต้องต่อให้ถูก

---

## E-stop — ตัด motor rail ไม่ใช่ตัด logic

รถรุ่นนี้ใช้ **motor rail 24 V** (24 V LiFePO4 20 Ah — [`../bom/poc-v3.md`](../bom/poc-v3.md#drivetrain))
ไม่ใช่ 12 V เดิม E-stop relay ต้อง**ทนกระแส peak >= 15 A** ที่ rail นี้
(poc-v3.md D5) — สูงกว่าเดิมมากเพราะมอเตอร์ใหญ่กว่าและ 35 kg ต้องการแรงบิดมากกว่า

```text
        แบต 24 V LiFePO4 20 Ah
              │
         ┌────┴────┐
         │ สวิตช์หลัก│
         │ + ฟิวส์  │  ◄── ตามสเปก driver จริง (ยังไม่เลือก part)
         └────┬────┘
              │
      ┌───────┴────────┬──────────────────┐
      │                │                  │
 ┌────┴─────┐    ┌─────┴─────┐      ┌─────┴─────┐
 │  E-stop  │    │ buck 5V   │      │ buck 5V   │
 │latching NC│   │  (Pi)     │      │ (logic)   │
 │peak >=15A│    └─────┬─────┘      └─────┬─────┘
 └────┬─────┘          │                  │
      ├──► sense ──────┼──────────────► ESP32 GPIO39
      │                ▼                  ▼
 ┌────┴─────┐         Pi              ESP32
 │ Motor    │
 │ driver   │   >= 10 A/ช่อง (poc-v3.md D2) + ตัวเก็บประจุที่ขาไฟเข้า
 └────┬─────┘
      ▼
  มอเตอร์ × 4  (24 V)
```

E-stop ต้อง **ตัดไฟมอเตอร์ทางกายภาพ** ส่วนสาย sense ที่ไป GPIO เป็นแค่
ให้ firmware รู้สถานะเพื่อรายงานขึ้น controller

E-stop ที่ทำงานผ่าน software อย่างเดียวไม่ใช่ E-stop — ถ้า firmware ค้าง
หรือ MCU แฮงค์ มอเตอร์จะยังหมุนต่อ

**Pi และ ESP32 ต้องไม่ถูกตัดไฟไปด้วย** ไม่งั้นจะรายงานสถานะไม่ได้
และ controller จะเห็นเป็น `communication_lost` แทน `emergency_stop` —
สองอย่างนี้ต้องการการจัดการต่างกัน

firmware ต้อง **ปฏิเสธ `reset`** ขณะที่ sense line ยัง active
ตอบ `error` code `emergency_stop` แทน `ack`

---

## Motor — ต่อขนานเป็นข้าง

skid-steer สั่งล้อหน้าและหลังข้างเดียวกันเหมือนกันเสมอ

```text
ช่อง A (LEFT)  ──┬── motor_fl
                 └── motor_rl

ช่อง B (RIGHT) ──┬── motor_fr
                 └── motor_rr
```

ถ้าใช้ driver 2 ช่อง (dual) แต่ละช่องต้องทน **stall ของสองมอเตอร์พร้อมกัน**
→ ต้องเลือก **≥ 10 A/ช่อง ที่ 24 V** (poc-v3.md D2) — ทางเลือกอื่นคือ driver
4 ช่อง (ช่องละมอเตอร์เดียว) ซึ่งยังต้อง ≥ 10 A/ช่องเท่ากัน เพราะ stall ของ
มอเตอร์แต่ละตัวเองก็อยู่เหนือกระแสใช้งานมากแล้ว

แลกกับ: คุมหน้า/หลังแยกไม่ได้ (ไม่ต้องใช้) และวัดกระแสต่อล้อไม่ได้ (ไม่ต้องใช้)

### ตรวจทิศทางก่อนปิดฝา

```text
drive(+100, 0)         → ล้อทั้ง 4 หมุนไปข้างหน้า
drive(+100, +40)       → ล้อขวาเร็วกว่าซ้าย  (เลี้ยวซ้าย = CCW)
```

ถ้าข้างใดกลับ ให้สลับสายคู่ของมอเตอร์นั้น หรือกลับใน firmware —
**เลือกแก้ใน firmware แล้วบันทึกไว้** จะได้ไม่สับสนตอนเปลี่ยนมอเตอร์

⚠️ ถ้า `omega > 0` ทำให้เลี้ยวขวาแทนซ้าย row follower จะกลายเป็น
**positive feedback** — rover จะออกนอกร่องเร็วขึ้นแทนที่จะกลับเข้าร่อง
นี่เป็นกับดักที่แพงที่สุดของ MVP

---

## Grounding

```text
แบต 24 V LiFePO4 ──┬── Motor driver VM (ผ่าน E-stop)
                   ├── buck 5V (Pi)      ──── Pi 5V
                   └── buck 5V (logic)   ──── ESP32 VIN

GND ─────── ต่อร่วมกันทั้งหมดที่จุดเดียว (star ground ที่ขั้วลบแบต)
```

GND ของ Pi, ESP32 และ driver **ต้องร่วมกัน** ไม่งั้นสัญญาณ UART และ PWM
จะไม่มีจุดอ้างอิงที่ถูกต้อง

แต่ห้องต่อพ่วงเป็นลูกโซ่ (daisy chain) — กระแสมอเตอร์ที่ไหลผ่าน GND ร่วม
จะสร้างแรงดันตกคร่อมที่ทำให้ ESP32 เห็น GND ไม่เท่ากับ Pi

---

## Cable Management

```text
[ ] สายกล้องขึ้นเสาต้องใช้ spiral wrap — เสาสั่นทำให้ภาพสั่น
[ ] สายมอเตอร์ (loom กระแสสูง ~10 A/เส้น ดู D2) แยกออกจากสาย UART และสายกล้อง
    ทั้งเส้นทาง — ไม่มัดรวมกัน ไม่วางขนานติดกันเป็นระยะยาว
[ ] สายทุกเส้นต้องไม่พันล้อตลอดการหมุน (ทดสอบด้วยมือ 360°)
[ ] เผื่อความยาวให้รถเคลื่อนที่ได้ ถ้ายังมีสายภายนอก (bench test)
```

สายมอเตอร์กระแสสูง (~10 A/เส้น ที่ 24 V) ที่เดินคู่กับสาย UART สัญญาณต่ำยาว ๆ
จะเหนี่ยวนำสัญญาณรบกวนเข้า serial ทำให้ JSON parse พลาดเป็นบางเฟรม — อาการจะ
โผล่เฉพาะตอนมอเตอร์หมุนเร็ว (กระแสสูงสุด) และจะดูเหมือนปัญหา latest-wins
ทั้งที่เป็นปัญหาสายไฟ ยิ่งกระแสสูงกว่าเครื่องเดโมเดิมมาก การแยก loom จึงสำคัญ
กว่าเดิม ไม่ใช่แค่ข้อแนะนำ

**ภาพสั่นจากเสากล้องที่โยกทำให้ valley histogram แกว่ง → `omega` กระตุก**
ซึ่งจะดูเหมือน gain สูงเกิน — ยึดเสาให้แน่นก่อน tune gain

---

## Verification

ก่อนจ่ายไฟ ดู [../mechanical/assembly.md](../mechanical/assembly.md#pre-power-checklist)

หลังจ่ายไฟ (ล้อลอย):

```text
[ ] อ่าน E-stop sense — กดแล้วค่าเปลี่ยน และไฟมอเตอร์ดับจริง
[ ] Pi และ ESP32 ยังมีไฟขณะ E-stop ถูกกด
[ ] UART สองทาง: Pi ส่ง drive → ESP32 ตอบ rover_state
[ ] หมุนมอเตอร์ทีละข้างช้า ๆ ตรวจทิศทาง
[ ] ถอดสาย UART → มอเตอร์ดับใน 300 ms
[ ] วัด wheel_v_min ทั้ง 4 ล้อ
```

รายการเต็ม: [../mechanical/assembly.md](../mechanical/assembly.md#bench-test-checklist--ล้อลอย-ขั้นที่-11)

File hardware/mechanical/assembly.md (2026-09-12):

# Assembly

ลำดับการประกอบ และค่าที่ **ต้องวัดระหว่างประกอบ** เพราะวัดทีหลังไม่ได้

---

## ลำดับ

```text
1. แผ่นแชสซี + ขายึดมอเตอร์
2. มอเตอร์ 4 ตัว + ล้อ
3. ตู้/ถาดอิเล็กทรอนิกส์ (วางให้ต่ำที่สุด)
4. H-bridge driver + ตัวเก็บประจุ
5. E-stop + สวิตช์หลัก + ฟิวส์
6. ESP32 + buck logic
7. Raspberry Pi + buck Pi
8. เสากล้อง + กล้อง 2 ตัว
9. แบตเตอรี่ (ต่ำสุดเท่าที่ทำได้)
10. เดินสาย + drag chain ไปเสากล้อง
11. **ทดสอบล้อลอยบนโต๊ะให้ผ่านครบ** ◄── ข้ามไม่ได้
12. วัดค่า + calibrate กล้องล่าง
13. วางลงแปลง
```

**ขั้นที่ 11 ข้ามไม่ได้** — ต่างจาก gantry ที่เคลื่อนที่เองไม่ได้ rover ที่วางลงพื้น
ก่อนทดสอบ safety คือ rover ที่อาจวิ่งหนีตอนที่การทดสอบล้มเหลว
ดู [../../docs/hardware.md](../../docs/hardware.md#hardware-in-the-loop--ต้องล้อลอย)

แบตเตอรี่และมอเตอร์ต้องอยู่ **ต่ำสุด** เพราะหัว mast อยู่ที่ 905 mm บนรถกว้างรวมล้อ
520 mm ทำให้จุดศูนย์ถ่วงสูงอยู่แล้ว

### ⚠️ 35 kg ไม่ใช่ของที่ยกคนเดียว

รถรุ่นนี้หนักประมาณ **35 kg ±20%** (ดู [`../bom/poc-v3.md`](../bom/poc-v3.md#มวลโดยประมาณ--35-kg-20))
ไม่ใช่เครื่องเดโมบนโต๊ะที่ยกคนเดียวได้อีกต่อไป

```text
[ ] ยกขึ้น-ลงโต๊ะ (ขั้นที่ 11) และ ขึ้น-ลงแปลง (ขั้นที่ 13) ใช้ **สองคน** เสมอ
    หรือใช้ทางลาด/รถเข็น — ไม่ยกคนเดียว
[ ] จุดจับต้องอยู่ที่โครงล่าง (z 125–250) ไม่ใช่ที่ mast หรือ body shell —
    mast สูง 500 mm ไม่ได้ออกแบบมารับน้ำหนักตัวรถ
[ ] วางแผนเส้นทางยกก่อนเริ่ม — 35 kg ที่หลุดมือกลางอากาศอันตรายกว่าของ 1 kg มาก
```

### ถอดล้อ/มอเตอร์ผ่าน bolt circle 60 mm

มอเตอร์ยึดกับโครงด้วย `motor_mount_bolt_circle_mm = 60` (4 × M5) ไม่ใช่รูคู่แบบ
มอเตอร์ขนาดเล็กเดิม — ถอดล้อหรือมอเตอร์แต่ละตัว:

```text
[ ] คลายน็อต 4 ตัวรอบ bolt circle 60 mm (ไม่ใช่สกรูยึดจุดเดียวกลางเพลา)
[ ] มอเตอร์นอกแพทเทิร์นนี้ต้องมีแผ่น adapter — ตรวจก่อนสั่งของ (ดู poc-v3.md D1)
[ ] ล้อ Ø250 หนักกว่าล้อเดิมมาก — รองรับน้ำหนักล้อก่อนคลายน็อตตัวสุดท้ายเสมอ
```

---

## ค่าที่ต้องวัดระหว่างประกอบ

| ค่า | วัดตอนไหน | บันทึกที่ |
|---|---|---|
| `wheel_diameter_mm` จริง (รวมยาง) | หลังใส่ล้อ | `config/rover.yaml` |
| `track_width_mm` จริง | หลังใส่ล้อ | `config/rover.yaml` |
| `body_width_mm` จริง (**จุดกว้างสุด**) | หลังใส่ล้อ | `config/rover.yaml` |
| `chassis_clearance_mm` จริง | หลังใส่ล้อ พร้อมน้ำหนักครบ | `config/rover.yaml` |
| **`wheel_v_min_mm_s`** (deadband) | ขั้นที่ 11 ล้อลอย | `config/rover.yaml` |
| `camera_down` homography | หลังติดกล้อง | `config/camera.yaml` |
| `soil_variation_mm` | หลังปรับหน้าดิน | `config/rover.yaml` |
| `runaway_budget_mm` ที่วัดได้จริง | หลังวางลงแปลง | `config/safety.yaml` |

`chassis_clearance` ต้องวัด **พร้อมน้ำหนักครบ** — ยางกดตัวลงหลายมิลลิเมตร
ค่าที่วัดตอนยกรถลอยจะสูงกว่าจริง แล้วท้องรถจะครูดยอดดินที่ invariant บอกว่าผ่าน

### `body_width_mm` — วัดที่จุดกว้างสุด ไม่ใช่แชสซีหรือ body shell

```text
       ◄──────────────── 520 ────────────────►
    ┌──┬──────────────────────────────────┬──┐
    │██│      โครงช่วงล้อ 340 mm           │██│    ██ = ล้อ ยื่นออกข้างละ 45 mm
    └──┴──────────────────────────────────┴──┘
```

ใช้เวอร์เนียร์วัดจากขอบยางซ้ายถึงขอบยางขวา **ไม่ใช่จากขอบโครงช่วงล้อ (340) และ
ไม่ใช่จากขอบ body shell (380)**

ถ้าบันทึกความกว้างโครง (340) หรือ body shell (380) ลง config แทนความกว้างรวม
(520) invariant ข้อ 5 จะผ่านโดยที่ล้อยังเบียดใบพืช — ระบบจะ "ดูเหมือนปลอดภัย"

### `wheel_v_min_mm_s` — ต้องวัด ไม่มีทางคำนวณ

ค่า 51 ใน config เป็นการเดาจาก 15% duty **ยังไม่ได้วัด**

```text
[ ] ยกล้อลอย จ่ายไฟมอเตอร์
[ ] สั่ง duty เริ่มจาก 0 เพิ่มขึ้นทีละ 1%
[ ] บันทึก duty ต่ำสุดที่ล้อเริ่มหมุนต่อเนื่อง (ไม่ใช่กระตุกครั้งเดียว)
[ ] ทำซ้ำทั้ง 4 ล้อ — ใช้ค่าที่แย่ที่สุด
[ ] wheel_v_min_mm_s = duty_min × wheel_v_max_mm_s
[ ] วางรถลงพื้นแล้ววัดซ้ำ — แรงเสียดทานพื้นทำให้ค่าสูงขึ้น ใช้ค่านี้
```

ถ้าค่าที่วัดได้ **เกิน 66.2 mm/s** → ต้องลด `omega_max_deg_s` (เพดานคือ ~29.0)
**ห้ามลด `wheel_v_min` เพื่อให้ invariant ผ่าน** — ค่านั้นเป็นคุณสมบัติของมอเตอร์
ไม่ใช่ค่าที่เราเลือก

### `soil_variation_mm`

หลังปรับหน้าดินเรียบที่สุดเท่าที่ทำได้ ให้วัดจริง:

```text
[ ] ขึงเชือกตึงตามแนวร่อง ให้เป็นระนาบอ้างอิง
[ ] วัดระยะจากเชือกลงถึงผิวดินทุก 100 mm ตลอด 2000 mm (20 จุด)
[ ] ทำ 2 ร่อง
[ ] soil_variation_mm = (สูงสุด − ต่ำสุด) / 2
```

ไม่ใช้ tool วัดเหมือน design gantry เพราะ MVP ไม่มี tool

ถ้าค่าที่วัดได้ **เกิน 62 mm** → invariant `wheel_diameter >= 4 × soil_variation`
ไม่ผ่าน ต้องเลือก: ปรับหน้าดินใหม่ หรือเปลี่ยนล้อใหญ่ขึ้น **ไม่ใช่แก้ config ให้ผ่าน**
(margin กว้างกว่าเดิมมาก — ล้อ Ø250 ให้ margin 190 mm ที่ `soil_variation_mm: 15`
จึงไม่ใช่จุดเสี่ยงหลักของเครื่องนี้แล้ว)

### `runaway_budget_mm` — วัดหลังวางลงแปลง

```text
[ ] วาง rover ในร่อง ให้กันชนหน้าอยู่ตำแหน่งเริ่มต้นปกติ
[ ] วัดระยะจากกันชนหน้าถึงขอบแปลงปลายร่อง
[ ] วัดระยะจากด้านข้างล้อถึงใบพืชที่ยื่นเข้าร่องมากที่สุด
[ ] runaway_budget_mm ต้องเล็กกว่าทั้งสองค่า
```

ค่า 60 ใน config เป็นค่าตั้งต้น ถ้าวัดจริงแล้วน้อยกว่า ต้องลด `runaway_budget`
แล้ว **re-validate invariant safety ทั้งสองข้อ** ซึ่งอาจต้องลด `v_max`
หรือ `command_timeout_ms` ตามไปด้วย

---

## Tolerance ที่สำคัญ

| จุด | Tolerance | ทำไม |
|---|---|---|
| เพลาล้อทั้ง 4 ขนานกัน | ±0.5° | ไม่งั้น rover ไถลเฉียงตลอดเวลา row follower จะต้านมันทุกเฟรม |
| ล้อซ้าย/ขวาเส้นผ่านศูนย์กลางเท่ากัน | ±0.5 mm | ต่างกันทำให้วิ่งตรงแล้วเบี่ยง — อาการเหมือน gain ผิด แต่แก้ที่ gain ไม่ได้ |
| กล้องล่างขนานกับ soil plane | ±1° | มุมก้มทำให้ error จากดินไม่เรียบใหญ่ขึ้น |
| **กล้องหน้า มุมก้ม** | **±2°** | **กำหนด lookahead → กำหนด gain** เปลี่ยนแล้วต้อง tune ใหม่ |
| เสากล้องไม่โยก | — | ภาพสั่นทำให้ valley histogram แกว่ง → omega กระตุก |

### ล้อคนละขนาดคือกับดักที่หายากที่สุด

ล้อขวาใหญ่กว่าซ้าย 1 mm (1.5%) ทำให้ rover เบี่ยงซ้ายอย่างต่อเนื่องแม้สั่ง
`omega = 0` row follower จะชดเชยได้ (มันปิดลูปด้วยภาพ) แต่มันจะกิน
พิสัย `omega` ไปส่วนหนึ่งตลอดเวลา ทำให้ความสามารถในการแก้ error จริงลดลง

อาการจะดูเหมือน "gain ไม่พอ" ทั้งที่ปัญหาเป็น mechanical — **วัดล้อก่อน tune gain**

### เพลาไม่ขนานแก้ด้วย software ไม่ได้

skid-steer พึ่ง slip อยู่แล้ว ถ้าเพลาเฉียงด้วย ทิศทางการ slip จะไม่สมมาตร
ทำให้ `omega` ที่ได้ต่างกันระหว่างเลี้ยวซ้ายและเลี้ยวขวา — gain ตัวเดียว
ชดเชยไม่ได้ทั้งสองทาง

---

## Pre-power Checklist

ก่อนจ่ายไฟครั้งแรก:

```text
[ ] หมุนล้อทั้ง 4 ด้วยมือได้อิสระ ไม่ติดขัด ไม่ฝืด
[ ] ล้อทั้ง 4 แตะพื้นพร้อมกันบนพื้นเรียบ (ไม่มีล้อลอย)
[ ] วัดล้อทั้ง 4 — เส้นผ่านศูนย์กลางต่างกันไม่เกิน 0.5 mm
[ ] วัด body_width ที่จุดกว้างสุด (ขอบยางถึงขอบยาง) แล้วบันทึกลง config
[ ] สายไม่พันกับล้อตลอดการหมุน
[ ] E-stop ตัดไฟมอเตอร์ได้จริง (วัดด้วยมิเตอร์ ไม่ใช่เชื่อวงจร)
[ ] E-stop **ไม่** ตัดไฟ Pi และ ESP32 (วัดด้วยมิเตอร์)
[ ] ขั้วไฟไม่กลับ วัดแรงดันก่อนเสียบ Pi และ ESP32
[ ] ตัวเก็บประจุ 1000 µF ขั้วถูกต้อง
[ ] GND ของ Pi, ESP32, driver ต่อร่วมกันที่จุดเดียว
```

การทดสอบ E-stop ด้วยมิเตอร์ก่อนจ่ายไฟจริงเป็นขั้นที่ข้ามไม่ได้ —
E-stop ที่ต่อผิดจะดูเหมือนทำงานจนถึงวันที่ต้องใช้จริง

**และต้องทดสอบทั้งสองทิศทาง**: ตัดมอเตอร์ได้ **และ** ไม่ตัด logic
ถ้าตัด logic ด้วย จะได้ rover ที่หยุดจริงแต่เงียบ — controller จะเห็นเป็น
`communication_lost` แทน `emergency_stop`

---

## Bench Test Checklist — ล้อลอย (ขั้นที่ 11)

ยกล้อลอยบนโต๊ะ ให้ผ่านครบก่อนวางลงพื้น

```text
Firmware / safety
[ ] ถอดสาย serial ระหว่างวิ่ง → มอเตอร์ดับภายใน 300 ms (วัดด้วย scope / log)
[ ] กด E-stop ขณะ Pi ยังส่ง drive → ล้อหยุด
[ ] ปล่อย E-stop แล้วสั่ง reset ขณะยังกดอยู่ → ถูกปฏิเสธ
[ ] ยัด drive 50 ตัวเข้า buffer → ใช้ตัว seq สูงสุดตัวเดียว
[ ] ส่ง seq ย้อนหลัง → ถูกทิ้ง
[ ] ปิด-เปิด ESP32 → uptime_ms ลดลง controller ตรวจจับได้

Motion
[ ] ตรวจทิศทาง: drive(+100, 0) → ล้อทั้ง 4 หมุนไปข้างหน้า
[ ] ตรวจทิศทาง: drive(0 < v, omega > 0) → ล้อขวาเร็วกว่าซ้าย (เลี้ยวซ้าย)
[ ] วัด wheel_v_min ทั้ง 4 ล้อ → ใช้ค่าแย่สุด
[ ] re-validate invariant drive ตัวล่างด้วยค่าที่วัดได้

Power
[ ] สั่งออกตัวเต็มกำลัง → แรงดันที่ Pi ไม่ตกต่ำกว่า 4.8 V
[ ] Pi ไม่รีบูตตลอดการทดสอบ
```

### ทิศทางที่กลับด้านคือกับดักที่แพงที่สุด

ถ้า `omega > 0` ทำให้เลี้ยว **ขวา** แทนซ้าย row follower จะกลายเป็น
positive feedback — rover จะออกนอกร่องเร็วขึ้นแทนที่จะกลับเข้าร่อง

แก้ได้ทั้งใน firmware หรือสลับสายมอเตอร์ — **เลือกแก้ใน firmware แล้วบันทึกไว้**
จะได้ไม่สับสนตอนเปลี่ยนมอเตอร์

ดู [coordinate-frames.md](coordinate-frames.md#rover--frame-หลักของ-mvp) สำหรับ sign convention

---

## หลังวางลงแปลง

```text
[ ] วัด runaway_budget จริง แล้วบันทึก
[ ] calibrate camera_down → บันทึก homography + error ที่วัดได้
[ ] วัด soil_variation → re-validate invariant geometry
[ ] tune gains.esp32 ใน config/control.yaml  (ค่า null จะทำให้ไม่ start)
[ ] วัด max_lateral_error จริงระหว่างวิ่ง → re-validate corridor
```

ดู [../electrical/power.md](../electrical/power.md) และ
[../electrical/wiring.md](../electrical/wiring.md)

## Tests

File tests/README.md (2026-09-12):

# tests

Framework: **pytest** · Scenario format: **YAML**

---

## Layout

```text
tests/
├── unit/            # pure logic — ไม่ต้องเปิด Isaac Sim
├── integration/     # Controller + FakeRover / Bridge + ESP32 Emulator
├── simulation/      # Controller + IsaacRover + Isaac Sim
└── scenarios/       # YAML scenario definitions
```

---

## Unit Tests

`backend: fake` — ไม่จำเป็นต้องเปิด Isaac Sim

ครอบคลุม:

```text
row follower  (RowEstimate → v, omega)
closed-loop convergence ด้วย FakeRover     ◄── ดู §Closed Loop
skid-steer mixing + saturation
startup invariants (9 ข้อ ทีละข้อ)
ExG + Otsu + absolute floor
valley finder
weed detector corridor filter
state transition
protocol encoding (streaming vs discrete)
seq tracker / link_age_ms
coordinate transform round-trip (กล้องล่าง)
CAD ↔ config sync
```

### `get_drive_state()` ต้องคืน key ชุดเดียวกันทุก backend

```python
def test_drive_state_shape_matches_across_backends():
    keys = {frozenset(r.get_drive_state()) for r in (FakeRover(), IsaacRover(), Esp32Rover())}
    assert len(keys) == 1
```

ถ้า `FakeRover` เผลอ expose `pose` ออกมา test นี้จับได้ทันที — ป้องกัน code
ที่เขียนตอน V0 พึ่งพา pose แล้วพังตอนเปลี่ยนเป็น `esp32`

---

## Closed Loop โดยไม่ต้องมีกราฟิก

ส่วนที่คุ้มที่สุดของ test suite นี้ และ gantry ทำไม่ได้

```text
FakeRover        integrate (v, omega) → pose ภายใน    (kinematic only)
FakeRowSensor    pose + สมการเส้นร่อง → RowEstimate
RowFollower      RowEstimate → (v, omega)
                        └──> วนกลับเข้า FakeRover
```

```python
def test_converges_from_offset():
    sim = FakeLoop(row=straight_row(), start_offset_mm=60, start_heading_deg=15)
    sim.run(seconds=3.0)
    assert abs(sim.history[-1].lateral_err) < 0.1
    assert sim.min_clearance_mm > 0        # ไม่เบียดต้นพืชระหว่างทาง
```

รันในหลักมิลลิวินาที อยู่ใน CI ได้ ตอบคำถาม *"gain ชุดนี้ลู่เข้าไหม
และแกว่งเกินร่องไหม"* **ก่อนแตะ Isaac เลย**

`min_clearance_mm > 0` สำคัญเท่า `lateral_err` — gain ที่ลู่เข้าเร็วแต่แกว่ง
เกินร่องระหว่างทางคือ gain ที่พาไปชนต้นพืช test ที่ดูแค่ค่าสุดท้ายจะปล่อยผ่าน

---

## Golden Mixing Vectors — test ข้ามภาษา

สูตร skid-steer mixing ถูก implement 2 ที่ที่แชร์โค้ดกันไม่ได้

```text
config/drive_mixing_vectors.csv     ◄── source of truth เดียว
        │
        ├──> tests/unit/test_drive_mixing.py          Python / IsaacRover
        └──> firmware/esp32/test/test_mixing.cpp      C++ / PlatformIO native
```

```bash
pytest tests/unit/test_drive_mixing.py
pio test -e native -d firmware/esp32
```

ทั้งสองต้องผ่านตารางเดียวกัน **ห้ามแก้ค่าในตารางเพื่อให้ test ผ่าน** — แก้ implementation

ตารางมี row ที่ทดสอบ saturation (`500, 25`) ซึ่งต้อง scale ทั้งสองข้าง
ไม่ใช่ clip ข้างเดียว — ที่ track 430 กับ `wheel_v_max` 327 แถวนี้ให้
`v_left`/`v_right` ก่อน scale เป็น 406.189/593.811 mm/s ซึ่งเกิน 327 ทั้งคู่
scale ด้วยอัตราส่วนเดิมจนล้อที่เร็วกว่าแตะเพดานพอดี ให้ `223.680 / 327.000`
(ดู [`config/drive_mixing_vectors.csv`](../config/drive_mixing_vectors.csv))
จึงแยกได้ชัดว่า implementation scale หรือ clip

---

## Startup Invariants — test ละข้อ

invariant 9 ข้อ ต้องมี test ที่ **ป้อนค่าที่ขัดกันแล้วยืนยันว่า fail จริง**
ไม่ใช่แค่ test ว่าค่าปัจจุบันผ่าน

```python
@pytest.mark.parametrize("override, expect_in_message", [
    ({"safety.runaway_budget_mm": 20}, "runaway_budget"),
    ({"bed.row_spacing_mm": 250}, "clear_furrow"),
    ({"rover.drive.omega_max_deg_s": 60}, "wheel_v_min"),
    ({"rover.wheel_diameter_mm": 40}, "soil_variation"),
    ...
])
def test_invariant_rejects_bad_config(override, expect_in_message):
    with pytest.raises(ConfigInvalid) as e:
        startup_checks.run(config_with(override))
    assert expect_in_message in str(e.value)
```

Test ต้องยืนยันว่า **error message มีค่าที่ขัดกันเป็นตัวเลข** ไม่ใช่แค่ชื่อ invariant —
เพราะจุดประสงค์ของ invariant คือบอกคนแก้ว่าต้องแก้อะไร

สามค่าใน `parametrize` ข้างบน (`250`, `60`, `40`) คือค่าที่ **เคยถูกตั้งไว้จริง
ตอนร่าง spec** แล้ว invariant จับได้ — เก็บเป็น regression test

---

## Integration Tests

```text
Controller + FakeRover
```

หรือ:

```text
Controller + Bridge + ESP32 Emulator
```

`bridge/simulator.py` ต้องเลียนพฤติกรรมที่ firmware จริงต้องมี ไม่ใช่แค่ตอบ ack:

```text
[ ] command timeout → motors_enabled: false
[ ] latest-wins (ยัด drive หลายตัว ใช้ seq สูงสุด)
[ ] ทิ้ง seq ย้อนหลัง
[ ] stop / emergency_stop override drive ในรอบเดียวกัน
[ ] ปฏิเสธ reset ขณะ estop sense ยัง active
[ ] uptime_ms ลดลงเมื่อจำลองรีบูต
```

Emulator ที่ตอบ ack ทุกอย่างแบบสุภาพจะทำให้ integration test ผ่านหมด
แล้วไปพังที่ V3 ซึ่ง debug แพงกว่ามาก

---

## Simulation Tests

```text
Controller + IsaacRover + Isaac Sim
```

ทดสอบ physics และพฤติกรรมของ rover จริง — ล้อบน heightfield, slip, ล้อลอย

---

## Scenario Tests

`tests/scenarios/`

```text
row_straight.yaml
row_curved.yaml
row_tilted_start.yaml
crop_gap_midrow.yaml
row_end.yaml
row_lost.yaml
soil_rough.yaml
link_lost.yaml
estop_during_drive.yaml
weed_in_furrow.yaml
```

| Scenario | ทดสอบ |
|---|---|
| `row_straight.yaml` | baseline — ตามร่องตรง 2000 mm ได้ |
| `row_curved.yaml` | ตาม `row_curvature_mm` ได้โดยไม่เบียดต้นพืช |
| `row_tilted_start.yaml` | เริ่มเอียง 15° ต้องเข้าร่องได้ |
| `crop_gap_midrow.yaml` | ช่องว่างกลางแถว → **ต้องไม่หยุด** |
| `row_end.yaml` | สุดร่อง → `STOPPED(row_end_suspected)` |
| `row_lost.yaml` | ถอดแถวกลางทางแต่ยังมีเขียว → `ERROR(row_lost)` |
| `soil_rough.yaml` | ±15 mm ล้อลอย ต้องยังตามร่องได้ |
| `link_lost.yaml` | Pi ↔ ESP32 หลุด → มอเตอร์ดับใน `command_timeout_ms` |
| `estop_during_drive.yaml` | กด E-stop ระหว่างวิ่ง |
| `weed_in_furrow.yaml` | detect วัชพืชในร่องได้ตามเกณฑ์ precision/recall |

### `crop_gap_midrow` กับ `row_end` เป็นคู่ตรงข้าม

ทั้งสองคือ "`green_fraction` ตก" แต่ต้องได้ผลต่างกัน:

```text
ช่องว่างกลางแถว   green ตกชั่วคราว   → ต้องวิ่งต่อ
สุดร่อง           green หมดถาวร     → ต้องหยุด
```

**ต้องผ่านทั้งคู่** — ผ่านข้างเดียวแปลว่า threshold ตั้งเอาใจข้างเดียว
และจะพังในแปลงจริงที่มีทั้งสองอย่าง

### Example — row curved

```yaml
name: row-curved

bed:
  bed_length_mm: 2000
  row_spacing_mm: 750
  row_curvature_mm: 40
  crop_gap_probability: 0

rover:
  start:
    lateral_offset_mm: 0
    heading_deg: 0

expect:
  final_state: STOPPED
  stop_reason: row_end_suspected
  distance_travelled_mm: { min: 1900 }
  min_clearance_mm: { min: 10 }
  max_lateral_error_mm: { max: 40 }     # ยืนยันสมมติฐานของ corridor
```

### Example — crop gap mid-row

```yaml
name: crop-gap-midrow

bed:
  bed_length_mm: 2000
  crop_gap_probability: 0.08
  gap_features:
    - at_mm: 1000
      length_mm: 240          # ต้นหาย 3 ต้นติดกัน

expect:
  final_state: STOPPED
  stop_reason: row_end_suspected     # หยุดที่ปลายร่อง ไม่ใช่ที่ช่องว่าง
  stopped_before_mm: { min: 1900 }   # ◄── ไม่หยุดที่ 1000
  error_code: null
```

### Example — estop during drive

```yaml
name: estop-during-drive

events:
  - at: 1.5
    set:
      estop: true

expect:
  final_state: ESTOP
  motors_enabled: false
  commanded_after_estop: { v_mm_s: 0 }
```

---

## Scenario ที่ตัดออกจาก design gantry

```text
weed_near_x_min · weed_near_x_max     ไม่มี workspace X/Y
endstop_failure                       ไม่มี endstop
motor_timeout                         → link_lost
camera_delay                          → camera_timeout (ยังมี แต่รวมใน link/timeout suite)
normal_bed_10_weeds · 100_random_weeds  → weed_in_furrow (วัดด้วย precision/recall ต่อเฟรม)
soil_high_spot · soil_low_spot        ต้องมี tool  → กลับมาที่ M3
weed_inside_crop_row                  ต้องมี in-row detection  → กลับมาที่ M3
crop_row_misaligned                   → row_curved (ครอบคลุมกว่า)
```

`soil_high_spot` / `soil_low_spot` / `weed_inside_crop_row` **ไม่ถูกลบทิ้ง** —
ยกไปที่ M3 พร้อม tool นิยามเดิมใน
spec แปลงดินรุ่นก่อน §9 (ลบออกจาก tree แล้ว — อยู่ใน git history) ยังถูกต้อง

---

## เกณฑ์ต้องวัดได้

ทุก `expect` ในไฟล์ scenario ต้องเป็นค่าที่วัดได้ ไม่ใช่ "ทำงานได้"

```text
✓ min_clearance_mm: { min: 10 }
✓ per-frame precision: { min: 0.9 }
✗ row_following: works
```

และ weed detection วัดด้วย **per-frame precision/recall** ไม่ใช่จำนวนรวม —
ไม่มี odometry จึง dedupe ไม่ได้ `weed_log` นับ detection ไม่ใช่นับต้น
ตัวเลขรวมไม่มีความหมาย

---

## Automated Simulation Testing

```text
git push
   │
   ▼
CI Pipeline
   │
   ├── pytest tests/unit/           ◄── รวม closed loop, ไม่ต้องมี GPU
   ├── pio test -e native           ◄── mixing vectors ฝั่ง C++
   ├── pytest tests/integration/
   │
   ▼
Start Isaac Sim Headless
   │
   ▼
Run Scenarios × randomization seeds
   │
   ▼
PASS / FAIL
```

`tests/unit/` ต้องรันได้เร็วและไม่ต้องมี GPU — closed-loop convergence test
อยู่ในชั้นนี้ได้เพราะไม่มี physics และไม่มีภาพ นั่นคือเหตุผลที่ออกแบบ
`FakeRover` + `FakeRowSensor` แบบนั้น

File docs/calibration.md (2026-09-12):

# Calibration & Coordinate Transform

Module: `perception/calibration.py`

📐 นิยาม frame ทั้งหมด (`world` / `bed` / `rover` / `camera_front` / `camera_down`) และ
unit convention อยู่ที่ [../hardware/mechanical/coordinate-frames.md](../hardware/mechanical/coordinate-frames.md)
— อ่านก่อนแตะ code ในไฟล์นี้

---

## MVP calibrate กล้องเดียว

| | `camera_front` | `camera_down` |
|---|---|---|
| ใช้ทำ | row following | weed detection |
| Calibration | **ไม่มี** | intrinsic + homography |
| Accuracy target | – | **±20 mm** |

นี่คือความต่างที่ใหญ่ที่สุดจาก design gantry ซึ่งต้อง calibrate ให้แม่นกว่า
รัศมีหัว tool (±8 mm) เพราะมีอะไรต้องเล็ง

---

## ทำไมกล้องหน้าไม่ต้อง calibrate

`RowEstimate` เป็นค่า **image-space ล้วน**:

```python
lateral_err = (valley_near - u_center) / (width / 2)      # [-1, 1]
heading_err = (valley_far  - valley_near) / (width / 2)   # [-1, 1]
```

`heading_err` คำนวณจาก **ผลต่างของ valley สองระยะในภาพเดียวกัน** ซึ่งไม่ต้องรู้
focal length, ความสูงกล้อง หรือมุมก้มเลย

row follower ปิดลูปด้วยค่านี้โดยตรง — ไม่มีขั้นตอนไหนต้องแปลงเป็น mm

**ราคาที่จ่าย**: gain มีหน่วย `(deg/s) / unitless` จึงต้อง tune ไม่มีสูตรคำนวณจาก
เรขาคณิต และ gain **ผูกกับ `camera_front_tilt_deg`** เพราะมุมก้มกำหนด lookahead
ขยับขายึดกล้องแล้ว gain ใช้ไม่ได้

แลกกันแล้วคุ้ม: MVP ตัดงาน calibration ที่แม่นยำออกได้หนึ่งกล้อง และตัด
coordinate transform ออกจาก control path ทั้งหมด

---

## ทำไมกล้องล่างยังต้อง calibrate

MVP **ไม่มีอะไรกระทำต่อตำแหน่งวัชพืช** — ไม่มี tool ที่ต้องเล็ง
ถ้าจะเลื่อนงาน calibration ไป M3 ก็ดูมีเหตุผล

แต่ **ต้องทำตอนนี้** เพราะ:

```text
ต้องรู้ตัวเลข error budget จริงบนดิน ±15 mm ก่อนออกแบบ tool
ไม่ใช่หลังจากสร้าง tool แล้วพบว่าเล็งไม่เข้า
```

M3 ต้องเลือกรัศมีหัว tool จากตัวเลขนี้ — ถ้าไม่มีตัวเลข จะเลือกจากการเดา

---

## Pipeline (กล้องล่าง)

```text
camera_down
  │
  ▼
Image
  │
  ▼
ExG + Otsu + floor
  │
  ▼
Blobs
  │
  ▼
furrow_corridor filter + touches_side_edge filter
  │
  ▼
Pixel Coordinate (u, v)
  │
  ▼
Homography (soil reference plane)
  │
  ▼
Rover-frame Coordinate (x_mm, y_mm)
  │
  ▼
weed_log.jsonl
```

**สังเกตว่าไม่มี Motion Planner ที่ปลายทาง** — ปลายทางคือ log
นี่คือ observation path ไม่ใช่ control path

---

## Example

```text
u = 160, v = 200   →   x_mm = −25, y_mm = 120   (rover frame)
```

`x_mm = −25` แปลว่าอยู่ซ้ายของกึ่งกลาง rover 25 mm

**ไม่มีพิกัดในแปลง** — ไม่มี odometry จึงแปลง `rover → bed` ไม่ได้

---

## Calibration Steps

1. วาง calibration target (checkerboard) **บนแผ่นแข็งวางราบบนดิน**
2. Capture จาก `camera_down` ที่ตำแหน่งติดตั้งจริงบน rover
3. คำนวณ intrinsic (focal length, principal point, distortion)
4. คำนวณ homography ระหว่าง image plane และ **soil reference plane**
5. Verify ด้วยจุดที่รู้ตำแหน่งจริง — วัด error เป็น mm ทั้งจุดดินสูงและจุดดินต่ำ
6. บันทึกผลและ error budget ลง `config/camera.yaml`

ขั้นที่ 1 ต้องใช้แผ่นแข็ง เพราะวาง target ลงบนดินตรง ๆ จะเอียงตามความไม่เรียบ
ทำให้ได้ homography ที่ผิดตั้งแต่ต้น

ขั้นที่ 2 ต้องทำ **บน rover ที่ประกอบเสร็จ** ไม่ใช่ถือกล้องวางไว้ —
ความสูงและมุมของขายึดจริงคือสิ่งที่ homography อธิบาย

---

## Soil Plane Error Budget

ดินไม่เรียบ ±`soil_variation_mm` (15 mm) แต่ homography สมมติว่าทุกจุดอยู่บน
plane เดียว → จุดที่สูงหรือต่ำกว่า reference plane จะถูก project ผิดตำแหน่ง

```text
     กล้อง
       │ ╲
       │  ╲  แนวสายตา
       │   ╲
───────┼────╳──────  reference plane  → ตำแหน่งที่คำนวณได้
       │   ╱ ╲
       │  ╱   ╲
       │ ╱     ● จุดจริงบนยอดดิน
              └─ error
```

ขนาด error ขึ้นกับมุมมองกล้อง:

| การติดตั้ง | Error จากความไม่เรียบ |
|---|---|
| `camera_down` top-down | เล็กสุด แต่ไม่เป็นศูนย์ที่ขอบเฟรม |
| เอียงทำมุม | ใหญ่ขึ้นตามมุม |

`camera_down` ตั้งให้มองตรงลง **โดยเจตนา** เหตุผลเดียวกับ `camera_tilt_deg = 0`
ของ design gantry — ยิ่งเอียงยิ่งแย่

**ต้องวัดจริง ไม่ใช่ประมาณ** — เอา marker ที่รู้ตำแหน่งไปวางทั้งจุดสูงและจุดต่ำ
แล้ววัดว่าค่าที่คำนวณได้เพี้ยนไปกี่ mm

### Error ที่ยอมรับได้ใน MVP: ±20 mm

ผ่อนจาก ±8 mm ของ design gantry เพราะ MVP ไม่มี tool ที่ต้องเล็ง
ตัวเลข mm ใช้แค่บันทึกขนาด/ตำแหน่งคร่าว ๆ ใน `weed_log`

ถ้าวัดจริงแล้วเกิน 20 mm:

1. ยืนยันว่ากล้องตั้งตรงลงจริง (±1°)
2. ปรับหน้าดินให้เรียบขึ้น → ลด `soil_variation_mm`
3. ลดความสูงกล้อง (แลกกับ FOV ที่แคบลง — ต้องยังครอบ corridor 210 mm)

**ห้ามแก้ `error_budget_mm` ในไฟล์ config เพื่อให้ "ผ่าน"** — ค่านั้นคือ target
ที่ M3 จะใช้ตัดสินขนาดหัว tool ค่าที่วัดได้ต้องบันทึกแยกเป็นค่าที่วัดได้

---

## Verification

Round-trip test ใน `tests/unit/`:

```text
rover-frame (x, y) → expected pixel → transform back → rover-frame (x, y)
```

Scenario test บนดินไม่เรียบ:

```text
tests/scenarios/soil_rough.yaml
tests/scenarios/weed_in_furrow.yaml
```

ยืนยันว่า error ที่เกิดจริงยังอยู่ใน budget และ `weed_detector` ยังได้
per-frame precision/recall ตามเกณฑ์

---

## สิ่งที่ MVP ไม่มี: `bed` frame

```text
world → bed  ┄┄ ไม่มี ┄┄  rover ──┬─► camera_front
                                   └─► camera_down
```

`bed → rover` **ไม่มีใครรู้ค่า runtime** เพราะไม่มี localization

ผลคือ calibration ของ MVP หา `camera_down → rover` เท่านั้น — **ไม่ใช่**
`camera → bed` เหมือน design gantry

ใครเขียน code ที่ต้องการพิกัดใน `bed` frame ต้องหยุดแล้วไปทำ **M2 (encoder)**
ไม่ใช่เดาค่ามาเติม ดู [../hardware/mechanical/coordinate-frames.md](../hardware/mechanical/coordinate-frames.md)

---

## Sim vs Real

Isaac Sim camera ให้ ground-truth intrinsic, pose และ **ความสูงจริงของทุกจุดบนดิน** —
ใช้วัด projection error ได้แม่นยำโดยไม่ต้องวัดมือ เป็นวิธีที่ถูกที่สุดในการหา
error budget ก่อนมี hardware

เมื่อเปลี่ยนไปใช้กล้องจริง ให้ calibrate ใหม่แล้วเปลี่ยนแค่ `config/camera.yaml`
โดยไม่แก้ code

⚠️ **gain ของ row follower ไม่โอนจาก sim ไป hardware** แม้ calibration จะโอนได้ —
slip ของ skid-steer ต่างกัน ดู [../config/README.md](../config/README.md#controlyaml)

---

## Tools

`tools/calibration/` — script ช่วย capture, solve, visualize
และ **plot error map ทั่วเฟรม** เพื่อหาโซนที่ error เกิน budget

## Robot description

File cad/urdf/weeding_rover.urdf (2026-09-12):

<?xml version="1.0"?>
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
<robot name="weeding_rover">

  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
  <link name="base_link">
    <inertial>
      <origin xyz="0.00000 0.00000 0.22189" rpy="0 0 0"/>
      <mass value="27.800000"/>
      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
    </inertial>
    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
  </link>

  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

  <link name="wheel_fl_link">
    <inertial>
      <origin xyz="0.00000 0.00000 0.00000" rpy="0 0 0"/>
      <mass value="1.800000"/>
      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
    </inertial>
    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
  </link>

  <joint name="wheel_fl" type="continuous">
    <parent link="base_link"/>
    <child link="wheel_fl_link"/>
    <origin xyz="0.200 0.215 0.125" rpy="0 0 0"/>
    <axis xyz="0 1 0"/>
    <limit effort="10.0" velocity="2.616"/>
    <dynamics damping="0.0" friction="0.0"/>
  </joint>

  <link name="wheel_fr_link">
    <inertial>
      <origin xyz="0.00000 0.00000 0.00000" rpy="0 0 0"/>
      <mass value="1.800000"/>
      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
    </inertial>
    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
  </link>

  <joint name="wheel_fr" type="continuous">
    <parent link="base_link"/>
    <child link="wheel_fr_link"/>
    <origin xyz="0.200 -0.215 0.125" rpy="0 0 0"/>
    <axis xyz="0 1 0"/>
    <limit effort="10.0" velocity="2.616"/>
    <dynamics damping="0.0" friction="0.0"/>
  </joint>

  <link name="wheel_rl_link">
    <inertial>
      <origin xyz="0.00000 0.00000 0.00000" rpy="0 0 0"/>
      <mass value="1.800000"/>
      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
    </inertial>
    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
  </link>

  <joint name="wheel_rl" type="continuous">
    <parent link="base_link"/>
    <child link="wheel_rl_link"/>
    <origin xyz="-0.200 0.215 0.125" rpy="0 0 0"/>
    <axis xyz="0 1 0"/>
    <limit effort="10.0" velocity="2.616"/>
    <dynamics damping="0.0" friction="0.0"/>
  </joint>

  <link name="wheel_rr_link">
    <inertial>
      <origin xyz="0.00000 0.00000 0.00000" rpy="0 0 0"/>
      <mass value="1.800000"/>
      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
    </inertial>
    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
  </link>

  <joint name="wheel_rr" type="continuous">
    <parent link="base_link"/>
    <child link="wheel_rr_link"/>
    <origin xyz="-0.200 -0.215 0.125" rpy="0 0 0"/>
    <axis xyz="0 1 0"/>
    <limit effort="10.0" velocity="2.616"/>
    <dynamics damping="0.0" friction="0.0"/>
  </joint>

  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
  <link name="camera_front_link">
    <inertial>
      <origin xyz="0 0 -0.00575" rpy="0 0 0"/>
      <mass value="0.004000"/>
      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
    </inertial>
    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
  </link>

  <joint name="camera_front" type="fixed">
    <parent link="base_link"/>
    <child link="camera_front_link"/>
    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
    <origin xyz="0 0 0.850" rpy="-2.4434609528 0 -1.5707963268"/>
  </joint>

  <link name="camera_down_link">
    <inertial>
      <origin xyz="0 0 -0.00575" rpy="0 0 0"/>
      <mass value="0.004000"/>
      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
    </inertial>
    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
  </link>

  <joint name="camera_down" type="fixed">
    <parent link="base_link"/>
    <child link="camera_down_link"/>
    <origin xyz="0 0 0.850" rpy="3.1415926536 0 -1.5707963268"/>
  </joint>

</robot>

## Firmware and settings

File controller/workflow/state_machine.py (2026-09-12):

"""The rover's states and the transitions between them (spec §5.3).

This module owns transitions and nothing else.  It does not drive, does not
read a camera, does not sleep and holds no clock — every transition is a call
from outside.  That is what lets the whole table be tested as arithmetic,
without a rover and without an image.

Two distinctions are load-bearing:

``STOPPED`` is not a fault.  It is the normal end of a run waiting for a human
to acknowledge it, and it carries a ``stop_reason`` with no error code.  The
scenario contract is ``final_state: STOPPED``, ``stop_reason:
row_end_suspected``, ``error_code: null`` — modelling the end of a row as an
error would make ``row_end`` and ``crop_gap_midrow`` indistinguishable at the
one point where they have to differ.

``ESTOP`` is reachable from every state, ``BOOT`` and ``ERROR`` included: the
button cuts the motor rail electrically, wherever the software happens to be.
Leaving it takes two separate things — the button released *and* an ack — so
that software cannot ack its way past a button somebody is still holding down.

Where the events come from
--------------------------
``ROW_END`` and ``ROW_LOST`` are raised by ``controller.safety.runaway``, the
controller's own safety layer.  ``LINK_LOST``, ``CAMERA_TIMEOUT``,
``COMMAND_TIMEOUT`` and ``COMMUNICATION_LOST`` are drawn by §5.3 and so the
edges exist here, but **nothing in V0 raises them**: their detectors are the
link monitor and the protocol codec, which are V3 work.  The edges are the
contract those detectors will be written against; a half-built detector left
in this module would read like a working one.
"""

from __future__ import annotations

from enum import Enum

#: The reason recorded on a normal stop.  Named as a suspicion on purpose:
#: green_fraction is a heuristic, not a measurement, and nothing before V1 has
#: rendered images to check it against (§5.4).
ROW_END_SUSPECTED = "row_end_suspected"


class RoverState(Enum):
    BOOT = 1
    READY = 2
    DRIVING_ROW = 3
    STOPPED = 4  # normal end of a run, waiting for a human ack
    ERROR = 5
    ESTOP = 6


class ErrorCode(Enum):
    """The codes of spec §8.5 that this machine can land in ERROR or ESTOP with."""

    ROW_LOST = "row_lost"
    LINK_LOST = "link_lost"
    CAMERA_TIMEOUT = "camera_timeout"
    COMMAND_TIMEOUT = "command_timeout"
    CONFIG_INVALID = "config_invalid"
    COMMUNICATION_LOST = "communication_lost"
    EMERGENCY_STOP = "emergency_stop"


class Event(Enum):
    """Everything that can move the machine.  All of it arrives from outside."""

    VALIDATE_OK = "validate_ok"
    VALIDATE_FAILED = "validate_failed"
    START = "start"
    ROW_END = "row_end"
    ROW_LOST = "row_lost"
    LINK_LOST = "link_lost"
    CAMERA_TIMEOUT = "camera_timeout"
    COMMAND_TIMEOUT = "command_timeout"
    COMMUNICATION_LOST = "communication_lost"
    ESTOP = "estop"
    ESTOP_RELEASED = "estop_released"
    ACK = "ack"


class IllegalTransition(Exception):
    """An event the current state has no edge for.

    Raised rather than ignored: a machine that silently drops a transition ends
    up somewhere nobody asked for, and the call site that fired the event goes
    on believing it landed.
    """


#: Faults out of DRIVING_ROW, and the code each one lands in ERROR with.
_FAULTS: dict[Event, ErrorCode] = {
    Event.ROW_LOST: ErrorCode.ROW_LOST,
    Event.LINK_LOST: ErrorCode.LINK_LOST,
    Event.CAMERA_TIMEOUT: ErrorCode.CAMERA_TIMEOUT,
    Event.COMMAND_TIMEOUT: ErrorCode.COMMAND_TIMEOUT,
    Event.COMMUNICATION_LOST: ErrorCode.COMMUNICATION_LOST,
}

#: Every edge §5.3 draws, minus the two that carry a condition or a payload:
#: ``ESTOP`` (legal from everywhere) and ``ACK`` out of ``ESTOP`` (needs the
#: button released first).  Both are handled explicitly in :meth:`fire`.
_TRANSITIONS: dict[tuple[RoverState, Event], RoverState] = {
    (RoverState.BOOT, Event.VALIDATE_OK): RoverState.READY,
    (RoverState.BOOT, Event.VALIDATE_FAILED): RoverState.ERROR,
    (RoverState.READY, Event.START): RoverState.DRIVING_ROW,
    (RoverState.DRIVING_ROW, Event.ROW_END): RoverState.STOPPED,
    **{(RoverState.DRIVING_ROW, event): RoverState.ERROR for event in _FAULTS},
    (RoverState.STOPPED, Event.ACK): RoverState.READY,
    (RoverState.ERROR, Event.ACK): RoverState.READY,
}


class StateMachine:
    """The transition table of §5.3, and the reason for the current state.

    ``stop_reason`` and ``error_code`` are separate fields rather than one
    ``reason``, because the scenario contract asserts them separately and a
    normal stop must report ``error_code: null``.
    """

    def __init__(self) -> None:
        self._state = RoverState.BOOT
        self._stop_reason: str | None = None
        self._error_code: ErrorCode | None = None
        self._estop_released = False

    @property
    def state(self) -> RoverState:
        return self._state

    @property
    def stop_reason(self) -> str | None:
        """Why the run ended normally.  ``None`` unless the state is STOPPED."""
        return self._stop_reason

    @property
    def error_code(self) -> ErrorCode | None:
        """Which §8.5 code put the machine in ERROR or ESTOP."""
        return self._error_code

    @property
    def estop_released(self) -> bool:
        """Whether the button has been reported released since it was pressed."""
        return self._estop_released

    def fire(self, event: Event) -> RoverState:
        """Apply ``event`` and return the resulting state.

        Raises :class:`IllegalTransition` — without changing anything — for any
        pair the diagram does not draw.
        """
        if event is Event.ESTOP:
            # Reachable from every state, BOOT and ERROR included, and it
            # re-latches: a button pressed again must not ride on the release
            # that came before it.
            self._state = RoverState.ESTOP
            self._stop_reason = None
            self._error_code = ErrorCode.EMERGENCY_STOP
            self._estop_released = False
            return self._state

        if self._state is RoverState.ESTOP:
            return self._fire_in_estop(event)

        destination = _TRANSITIONS.get((self._state, event))
        if destination is None:
            raise IllegalTransition(f"{self._state.name} has no edge for {event.value!r}")

        self._state = destination
        self._stop_reason = ROW_END_SUSPECTED if event is Event.ROW_END else None
        if event is Event.VALIDATE_FAILED:
            self._error_code = ErrorCode.CONFIG_INVALID
        else:
            self._error_code = _FAULTS.get(event)
        return self._state

    def _fire_in_estop(self, event: Event) -> RoverState:
        """Leaving ESTOP needs the button released *and* an ack, in that order.
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

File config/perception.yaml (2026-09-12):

# perception.yaml — ExG floor, confidence, loop rate, corridor, weed area
#
# `exg_floor` เป็นค่าเดียวใน pipeline ที่ต้อง tune ด้วยมือ — Otsu ต่อเฟรมจัดการ
# สีดินที่เปลี่ยนตามความชื้นเอง แต่เมื่อไม่มีสีเขียวในเฟรมเลย Otsu จะแบ่ง noise
# ออกเป็นสองกองแล้วคืน mask ที่ดูเหมือนมีพืช `exg_floor` เป็นพื้นกันข้อนี้
#
# `green_fraction_row_end` คือเส้นที่แยก `row_end` ออกจาก `row_lost` (§5.4) — อยู่ที่นี่
# เพราะมันเป็นสมบัติของ mask ที่ ExG ผลิต ถ้า `exg_floor` หรือ asset พืชเปลี่ยน ค่านี้ขยับตาม
#
# `max_lateral_error_mm` กำหนดความกว้าง corridor:
#   corridor = clear_furrow − 2 × max_lateral_error_mm = 690 − 80 = 610 mm
#
# กล้องล่างต้องครอบ corridor + ขอบข้างละ 20 = 650 mm ที่ความสูง 850 mm
#   HFOV ที่ต้องการ = 2 × atan(325 / 850) = 41.9°  ->  เลนส์ >= 45°

perception:
  loop_hz: 10                  # front camera / control loop
  camera_timeout_ms: 300

  exg:
    exg_floor: 12              # ต้อง tune ด้วยมือ — ดู config/README.md#exg_floor

  row_estimator:
    conf_min: 0.25             # valley prominence ขั้นต่ำ
    green_fraction_row_end: 0.10   # สมมติฐาน — ยังไม่ถูก validate ต้องวัดที่ V1
    front_downscale: [320, 240]

  weed_detector:
    max_lateral_error_mm: 40   # สมมติฐาน — ต้องวัดที่ V1
    min_weed_area_mm2: 60
    down_rate_hz: 2

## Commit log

2026-09-12 Pivot platform from fixed gantry to 4-wheel rover for first MVP
    Replaces the FarmBot-style gantry with a skid-steer 4WD rover carrying two
    cameras. Reverses D1 of the weeding-bed design, which had explicitly rejected
    a rover to avoid navigation/odometry work. The gantry is cancelled, not
    deferred.
    MVP scope is deliberately narrow: drive along a furrow using the front camera
    and detect weeds in the furrow using the down camera. No tool, no servo, no
    soil contact sensor. Weeding moves to M3 together with the whole tool design,
    which stays valid and is preserved in the history docs.
    Architecture that survived the change unmodified: layer boundaries, startup
    backend selection (fake/isaac/esp32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
    [drive_mixing_vectors.csv]
2026-09-12 Fix references left dangling by removing the weeding-table design doc
    The previous commit deleted mini-smart-weeding-table-repository-architecture.md
    but three docs still pointed at it, including a broken markdown link in the
    README's Design History table.
    - README: the row now names the file as plain text and says the content lives
    only in git history, instead of linking to a path that returns 404.
    - Rover MVP spec §12: the file moves from the "keep as history with a
    superseded banner" list to a "deleted" list, with the reason - it was
    superseded twice (table -> bed -> rover) and nothing in the remaining
    milestones reaches back into it.
    - Weeding-bed spec: its own Supersedes line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
2026-09-12 Close the control loop with FakeRowSensor and FakeLoop
    FakeRover integrates (v, omega), FakeRowSensor turns the pose back into a
    RowEstimate, RowFollower closes it. From 60 mm off-centre and 15 deg skewed
    away from the furrow, the config gains bring |lateral_err| under 0.1 in 2.1 s
    and never leave the furrow.
    min_clearance_mm matters as much as the final error, so it has a test that can
    actually fail: with gains of zero the same run drives 96 mm out and reports
    negative clearance.
    The harness lives in tests/ because FakeRowSensor reads FakeRover's internal
    pose, and test_layering.py now greps controller/motion, workflow and safety to
    keep that pose off the control path.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
2026-09-12 Add the nine startup invariants
    All nine run before any raise, so one startup shows everything that is wrong
    rather than one problem per attempt. Every message names the numbers in
    conflict and ends with the value to change -- an invariant that reports only
    its own name sends the reader back to the spreadsheet it replaced.
    Each invariant has a test that feeds it a contradictory config, including the
    four values actually set while drafting: row_spacing 250, omega_max 60,
    wheel_diameter 40 and track_width 140. The last of these is the odd one out --
    it never broke an invariant, it left a 4 mm clear-furrow margin -- so it is
    tested through margins() rather than as a failure it does not cause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
2026-09-12 Add ExG segmentation with Otsu and the absolute floor
    The floor is the point of the module. Otsu always returns a threshold, so a
    frame with no green in it gets split into noise-above and noise-below and comes
    back looking like vegetation -- which means green_fraction never drops and the
    end-of-row heuristic never fires.
    test_otsu_on_its_own_would_have_invented_plants proves the failure is real on
    the same bare-soil frame the floor rejects, so the guard is tested against what
    it actually prevents rather than against itself.
    A uniform frame is the mirror case: Otsu has no split to find, and left alone
    `exg > threshold` would mask nothing at all. Handled explicitly.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
2026-09-12 Add the C++ half of the golden mixing vectors
    The mixing formula is implemented twice in places that cannot share code.
    Until now only the Python side was held to config/drive_mixing_vectors.csv,
    so the table had exactly one reader — the drift it exists to prevent.
    test_mixing.cpp links src/mixing.cpp rather than carrying its own copy of the
    formula: build_src_filter admits mixing.cpp and nothing else into the native
    build, because a test with its own formula would only prove the two languages
    agree with the test file.
    The CSV path is relative to the PlatformIO project directory, which is where
    the runner starts the binary — verified by invoking pio from the repo root and
    watching ../.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
2026-09-12 Make the `# derived: cad` markers mean something
    config/README.md and scripts/README.md both tell the reader to run
    tests/unit/test_cad_config_sync.py, which did not exist, and the CSV it reads
    did not exist either. Until now the six markers in rover.yaml were comments.
    parameters.csv is the 16 parameters from cad/parameters/README.md transcribed,
    nothing invented.
    Not every marker is an equality. wheel_v_max_mm_s cites `cad wheel_diameter +
    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
    [parameters.csv]
2026-09-12 Add the RoverState machine that section 5.3 draws
    Six states, and every edge the diagram shows -- including the ones it does
    not, which are rejected rather than ignored. A dropped transition leaves the
    machine somewhere nobody asked for while the caller believes it landed.
    Two things the table has to get right:
    STOPPED is a normal end of run, not a fault. It carries stop_reason
    row_end_suspected and no error code, because that is what tells row_end apart
    from crop_gap_midrow in the scenario contract.
    ESTOP is reachable from every state, BOOT and ERROR included -- the button
    cuts the motor rail wherever the software happens to be -- and leaving it
    needs the button released *and* an ack.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
    [state_machine.py]
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2026-09-12 Write the schema and examples messages.md has always cited
    protocol/messages.md names schema.json and examples/ in its third line, and
    neither existed. The catalog stays the authority on why each message is shaped
    the way it is; the schema is the form another language's client can be held to,
    and the examples are payloads a fixture can start from.
    Every message object is closed, which is what makes the four mistakes worth
    catching actually fail: a drive carrying an id (Rule 4 scoped to discrete), a
    discrete command with no id, an unknown type, and a rover_state with the
    command flattened to top level. The last one is the one that would survive
    review: without an encoder, a top-level v_mm_s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
2026-09-12 Measure link age from last_seq without a shared clock
    bridge/seq_tracker.py: the Pi stamps each send with its own clock and subtracts
    with the same clock when the board echoes the seq back. The board copies a
    number, which is all §8.3 asks of it; its uptime_ms is for spotting a reboot and
    is never compared with anything here.
    The table evicts past safety.link_lost_ms, because ten entries a second kept
    forever is a leak in the process that has to last a field session. Eviction has
    one trap, and it is the reason for the horizon: a seq that has fallen out of the
    window must not be aged against the oldest entry still in the table. After a
    three-second gap in sending, that arrangement answers 0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
2026-09-12 Give Rule 4 its deadline, and keep drive out of the pending table
    bridge/protocol.py encodes and decodes both directions and holds the id
    correlation of discrete commands. drive is encoded and forgotten: it is sent at
    10 Hz for the length of a row, so one dropped frame in the pending table would
    become an ERROR and the table would grow by ten entries a second for the whole
    run. Rule 4 is scoped to stop / emergency_stop / reset, which is the protocol
    change spec 8.1 makes rather than an oversight in the catalog.
    Rule 4 never named its timeout, and neither of the two numbers in safety.yaml is
    an ack deadline: command_timeout_ms (300) is the ESP32 waiting for the next
    drive, link_lost_ms (500)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
2026-09-12 Emulate the board's behaviour, not a polite server
    bridge/simulator.py is the ESP32 as tests/integration/ needs it: the transport
    and the firmware in one object, no hardware, no Isaac. write_line only fills the
    buffer; nothing happens until tick() runs a round, which is what makes
    latest-wins testable rather than an accident of timing.
    One test per item on bridge/README.md's checklist, each of which fails if the
    emulator stops doing it:
    command timeout no drive for 300 ms and the motors die, on the board's own
    account, reported once as an error rather than as silence
    latest-wins 50 drives pushed into one round: the highest seq is applied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
2026-09-12 Notice the button, and leave the latching where it already is
    The sense line was carried end to end — the emulator reads it, rover_state
    publishes it, Esp32Rover stores it, get_drive_state() reports it — and then
    nobody read it. EmergencyStop is the last hop: an edge on the wire becomes
    Event.ESTOP going down and Event.ESTOP_RELEASED coming up.
    Edge-triggered, because the line stays active for as long as somebody holds
    the button. Firing every tick would re-latch a latch that never came up and
    bury the one press worth reading under a hundred repeats of it.
    It fires on the StateMachine rather than the RowRun: ESTOP is legal from BOOT
    and from ERROR, states in which there is no run to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
2026-09-12 Pick real parts, and let the invariants choose the motor
    The BOM specified requirements but no part numbers. Choosing actual parts
    turned two of those requirements into contradictions, and both were only
    visible once real dimensions were in hand.
    track_width 120 caps motor length at 47 mm. The wheel's inner face sits at
    ±47.5 mm, and the left and right motors reach toward each other from there.
    That rules out every gearmotor that is easy to buy — GA25-370 (~65 mm),
    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
    [drive_mixing_vectors.csv, parameters.csv]
2026-09-12 Measure the motor hole pitch instead of leaving the guess in
    motor_mount_pitch_mm was 18 mm and marked a guess in selected-parts.md. No
    config value derives from it, so test_cad_config_sync.py could never have
    caught it being wrong - it only checks that the row exists.
    Measured off the Pololu #3482 STEP: four M2.5 holes on the gearbox face plate
    at +/-7.5 mm on both axes, so opposite pairs are 15.0 mm apart. The #1138
    bracket agrees independently - its four clearance holes sit on the same
    7.5 mm radius - and Pololu's own copy for #1138 says the bracket ships with
    two M2.5 screws. Two separately drawn parts landing on the same number is
    the closest thing to a caliper available here.
    Co-A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
    [parameters.csv]
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2026-09-12 Simplify the sim meshes, because Isaac pays for every triangle
    cad/exports/README.md asks for meshes/ to be simplified and warns that a full
    CAD mesh in Isaac costs solver time without buying accuracy. Vertex-clustered
    off the Fusion STL: base_link 36892 -> 6125 triangles, wheel 5502 -> 1396.
    Authored in metres so the URDF reads them with no scale factor. A mesh in
    millimetres plus a forgotten scale attribute is the exact failure
    coordinate-frames.md#unit-convention warns about, and it is invisible until
    the robot is a thousand times the wrong size.
    The wheel mesh is visual only. Collision stays a cylinder primitive.
    [base_link.obj, base_link.stl, wheel.obj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]
2026-09-12 Describe the rover to Isaac, and test that it still matches CAD
    Four continuous wheel joints at (+/-0.060, +/-0.060, 0.035) m and two fixed
    camera joints, in the star topology cad/urdf/README.md specifies.
    The wheel z is 0.035, not the -0.0025 in that README's table. The table was
    computed for the 65 mm wheel and a base_link at chassis height; the wheel is
    70 mm now and base_link sits on the soil reference plane per
    coordinate-frames.md, which puts the axle exactly one wheel radius up. The
    same README says the real value must come out of Fusion rather than be worked
    out by hand, so it does.
    test_urdf_matches_cad.py closes the gap coordinate-frames.md#unit-convention
    had already named: it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
    [weeding_rover.urdf]
2026-09-12 Import the rover into Isaac, and throw away everything the importer writes
    scripts/import_urdf.sh regenerates sim/isaac/robots/rover/rover_base.usd from
    cad/urdf/weeding_rover.urdf under Isaac's own Python (3.12, which the repo's
    >=3.11 already allows).
    Two things about the importer are easy to get wrong and silent when you do.
    usd_path is a DIRECTORY, and left unset the importer writes USD next to the
    source URDF - dumping generated files into cad/urdf/. It also writes the asset
    as <out_dir>/<robot>/<robot>.usd with its payload layers beside it, referenced
    as ./payloads/base.usda relative to the USD file's own directory. Renaming the
    file to rover_base.usd without moving the payloads wi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
2026-09-12 Put the physics in the layer that survives the next CAD change
    rover.usd sublayers the generated rover_base.usd and carries everything the
    URDF cannot hold: drive type, stiffness, damping, wheel/ground friction,
    contact and rest offset, solver iteration counts, and the sleep thresholds.
    cad/README.md#two-usd-layers is explicit that losing this to a re-import is the
    failure the split exists to prevent, and friction is the value it names as the
    most expensive to re-tune.
    Stiffness is 0 on all four wheels. A velocity drive with any stiffness behaves
    like a position drive and the wheel fights its own target, with no error.
    maxForce is deliberately NOT here. It is the gearbox's continuous lim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
    [config.yaml]
2026-09-12 Convert body velocity to wheel velocity without writing the formula again
    wheel_adapter.py is the second of the two places in the system where units
    change (hardware/mechanical/coordinate-frames.md#unit-convention), and the only
    thing controller/rover/isaac_rover.py is allowed to talk to. It calls
    controller.rover.mixing and divides by the wheel radius. That is all it does.
    The skid-steer formula already exists twice - here and in C++ on the ESP32 -
    and both are pinned to config/drive_mixing_vectors.csv. A third copy would
    drift, and the drift would read as a rover that turns slightly wrong in
    simulation and correctly on hardware. So the adapter's tests are held to that
    same table rathe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
2026-09-12 Replace the IsaacRover skeleton with one that drives
    Construction stays side-effect free, so tests/unit/test_rover_backends.py can
    still build one with no GPU to check that its drive-state shape matches
    FakeRover and Esp32Rover. IsaacRover() with no adapter still raises
    NotImplementedError, which is what that file already asserts.
    stop() and emergency_stop() are not the same thing and now behave differently
    in simulation, because they are different on the rover. stop() is a controlled
    stop with the brake held: zero target, drive still engaged, the damping in
    rover.usd holding the wheel. emergency_stop() drops the joints' maximum effort
    to zero, because the real E-stop opens the motor rai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
2026-09-12 Stand the rover on flat ground and measure what it actually does
    world.py is Stage 2's whole scene: a ground plane and the rover. No
    heightfield, no crops, no cameras. It references robots/rover/rover.usd, never
    rover_base.usd - referencing the base loads a robot with no drive, no damping
    and no friction, and it looks like it loaded correctly.
    app.py drives the four Stage 2 cases and prints the commanded wheel targets
    beside the measured result, so "the wheels turn on command" carries numbers.
    At 60 Hz, 3 s per case:
    drive(100, 0) L= 2.8571 R= 2.8571 rad/s -> v= 98.2 mm/s omega= 0.00
    drive(0, 40) L=-1.1968 R= 1.1968 rad/s -> v= 10.0 mm/s omega= 2.28
    drive(320, 40)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
2026-09-12 Implement the coordinate-frames checklist the doc has been promising
    hardware/mechanical/coordinate-frames.md#verification ends with six checks and
    names tests/unit/test_coordinate_frames.py as where they live. The file did
    not exist, so the checklist was a promise. Five of the six are now tests; the
    sixth, the camera_down pixel round-trip, is an explicit skip rather than a
    quiet omission, because nothing calibrates that camera until V2.
    The one that matters most is the last: no code under controller/ or
    perception/ may ask Isaac where the rover is. test_layering.py checked three
    tokens; this checks the ways Isaac actually answers that question, including
    the prim wrappers that get_world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
2026-09-12 Take the elapsed time off the clock, because a step is not always a step
    Opening the GUI reported every speed at exactly twice its real value:
    drive(100, 0) came out as 198.3 mm/s instead of 98.2, and drive(320, 40) as
    340.9 instead of 167.2. The rover was driving correctly the whole time; only
    the arithmetic was wrong, which is the worst way for this to fail, because
    watching the window makes it look right.
    world.step(render=True) does not advance one physics step. It advances by the
    RENDERING period, running as many physics substeps as that takes. Measured:
    60 steps advance 1.0 s with render=False and 2.0 s with render=True, at 60 Hz
    physics and 30 Hz rendering. Counting steps and mul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
2026-09-12 Size the rover for the field instead of the bench
    Source spec puts the rover at 620 x 520 mm on wheel 250 mm, which is a
    different machine from the 200 x 145 mm one the repo has, not a bigger
    version of it. A 520 mm body cannot drive down a 350 mm furrow, so the
    row spacing has to move with it.
    Three numbers in the source spec do not close, and the design decides
    them rather than discovering them in Fusion: overall length 620 is
    impossible with wheelbase 400 and wheel 250 (it is 650), a 380 mm
    chassis hits the wheels by 20 mm a side in the wheel zone, and ground
    clearance 125 equal to the wheel radius is a layout rule, not a target.
    The wheels also decide where the down camera goes. Ther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
2026-09-12 Break the scale-up into nine gates the tests can hold
    The plan follows the failing tests rather than a file list: parameters.csv
    moves first, and test_cad_config_sync and test_urdf_matches_cad name what
    has not caught up. Each task states the scoped pytest command that is its
    own deliverable, so the intentional red between tasks 2 and 6 does not hide
    a real break.
    Two tests change their assumptions rather than their numbers, and both
    carry the reason: base_link collision is two boxes because the frame necks
    in to clear the wheels, and the mass ceiling is the new gearbox's torque
    limit rather than a 250:1 micro gearbox's 2.3 kg.
    Self-review caught the front camera roll. It was derived by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
2026-09-12 Account for the CAD files the plan was about to leave behind
    The first draft overwrote four .obj files and stopped, leaving five
    committed binaries that describe the 70 mm rover. Nothing reads them, so
    nothing would have failed - but wheel_70x25.stl is a file someone prints
    and weeding_rover.step is a file someone sends to a shop.
    Task 10 deletes the manufacturing exports and keeps rover.f3d, which is the
    parametric assembly a person edits from 70 to 250 rather than rebuilds.
    Three READMEs still call that file the source of truth for geometry; it is
    parameters.csv now, and they say so.
    Task 6 grows an STL writer so exports/meshes stops being half generated and
    half hand-exported. Both fo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
2026-09-12 Delete the parts list for a rover that no longer exists
    Removes the four committed manufacturing exports (weeding_rover.step,
    chassis.stl, weeding_rover_base.stl, wheel_70x25.stl) that still
    describe the Ø70 bench machine, after confirming no code, URDF, or
    config references them by name. cad/fusion/rover.f3d is kept — it is
    the parametric assembly a mechanical engineer edits from Ø70 to Ø250,
    not an artifact to retire — and now carries a banner in cad/README.md
    saying it has not been updated yet. cad/exports/README.md's opening is
    replaced with a two-source table (meshes/ from parameters.csv via the
    generator script; step/ and stl/ from the Fusion assembly), and
    hardware/README.md's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
    [chassis.stl, weeding_rover.step, weeding_rover_base.stl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]
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2026-09-12 Throw away the rover we are no longer building
    The Fusion assembly, the v2 BOM, the selected-parts list and the two
    superseded specs all described a 200 x 145 mm machine with O70 wheels.
    Nothing read them, which is exactly why they would have sat there.
    Deleting cad/fusion/rover.f3d means manufacturing geometry now has no
    source at all: exports/step/ and exports/stl/ stay empty until someone
    builds a new assembly, and the CAD docs say so plainly instead of
    pointing at a file that describes the wrong machine. Whoever builds it
    should shape it from parameters.csv, which was already the source of
    geometry and is now the only one.
    Also clears the last old-machine numbers that were still state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
    [parameters.csv, rover.f3d, weeding_rover.urdf]
2026-09-12 Give manufacturing geometry a source again
    7e91e59 deleted cad/fusion/rover.f3d and left exports/step/ and
    exports/stl/ empty on purpose: the old assembly described a 200 x 145 mm
    machine with O70 wheels, and shaping the new one from it would have
    carried that machine forward. This builds the replacement from
    parameters.csv instead, which was already the only source of geometry.
    48 user parameters, every sketch fully constrained, no feature in an
    error or warning state. Nothing is typed into a sketch: the three
    enforced relationships are driven expressions, and changing wheelbase_mm
    from 400 to 450 moves the wheels and the motor mounts together and takes
    overall_length_mm to 700 on its ow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
    [rover_base_v0.f3d, rover_base_v0.step, sensor_head.stl]
2026-09-12 Give the rover tyres that bite, without moving a controlled dimension
    The assembly on cloud had four plain Ø250 cylinders where the machine
    needs agricultural tread. Rebuilt the wheels: Ø214 carcass with filleted
    shoulders, dished rim (Ø136 x 22, five lightening holes, Ø60 hub boss
    recessed inside the tread), and 16 lugs per wheel in two staggered
    shoulder sets. Each lug is lofted between sections rotated 13 deg apart,
    so it sweeps like an R-1 chevron instead of sitting as a straight bar.
    Built once at front-left, then mirrored front/rear and left/right, which
    flips the chevron per side the way a real fitment does.
    The shell gets the wedge nose (70 back x 55 down). The top-front corner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
    [rover_base_v0.f3d, rover_base_v0.step]
2026-09-12 Give the wheel drive the torque to turn the rover we actually built
    Every turning command left all four wheels at exactly 0.000 rad/s. Straight
    line driving worked, so it read as a steering problem; it was a drive problem.
    On a velocity drive with no stiffness, damping IS the motor's torque/speed
    slope, and it — not maxForce — decides how much torque the drive may ask for:
    torque = damping x (target - actual). damping was 0.005 N·m·s/deg, inherited
    from the 1.038 kg rover along with the friction table below it, which caps the
    drive at 0.34 N·m. A 35 kg skid-steer needs ~0.92 N·m per wheel to scrub its
    wheels round, so the drive sat pinned at its ceiling and the wheels never broke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
    [config.yaml]
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
